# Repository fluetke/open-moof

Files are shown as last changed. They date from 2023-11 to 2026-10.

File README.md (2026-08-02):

---
description: An open resource for DIY repair of the Vanmoof S3.
---

# 👋 Welcome to openMOOF

{% hint style="info" %}
**Work in Progress:** These pages are still a work in progress, ymmv.
{% endhint %}

## Overview

openMOOF collects community knowledge about diagnosing, maintaining, and repairing VanMoof S3 bikes. Use the repair guides for step-by-step procedures, or consult the parts pages when looking for compatible replacements and printable parts.

The manual separates reference data, disassembly, assembly, maintenance, reverse engineering, and supporting files so that measurements and part details can be reused across procedures.

## Quick links

{% content-ref url="overview/what-we-do.md" %}
[Compatible spare parts](overview/what-we-do.md)
{% endcontent-ref %}

{% content-ref url="overview/our-features.md" %}
[3D printable parts](overview/our-features.md)
{% endcontent-ref %}

{% content-ref url="manual/README.md" %}
[Repair manual structure](manual/README.md)
{% endcontent-ref %}

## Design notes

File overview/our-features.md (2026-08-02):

---
description: >-
  The following parts were created by the community and can be 3D printed, there
  is no guarantee for the fit and finish of the printed parts.
---

# ✨ 3D Printable Parts

## Vanmoof S3 spare parts:

* Chainguard rear by manimi94 -> [https://www.thingiverse.com/thing:5386610](https://www.thingiverse.com/thing:5386610)
* Motor-plug cover by lukeabate -> [https://www.thingiverse.com/thing:4713548](https://www.thingiverse.com/thing:4713548)
* Kicklock-cap replacement by Vanmoof4Fun -> [https://www.thingiverse.com/thing:6149896](https://www.thingiverse.com/thing:6149896)
* Handlebar-adjustment rings by fluetke -> [https://www.printables.com/model/538758-handlebar-adjustment-ring-for-vanmoof-s3](https://www.printables.com/model/538758-handlebar-adjustment-ring-for-vanmoof-s3)
* rear-light S2/S3 by fluetke -> [https://www.printables.com/model/535079-rear-light-for-vanmoof-s2s3](https://www.printables.com/model/535079-rear-light-for-vanmoof-s2s3)
* front-fork-stem-assembly S3 by fluetke -> [https://www.printables.com/model/632454-vanmoof-s3-front-fork-stem-assembly](https://www.printables.com/model/632454-vanmoof-s3-front-fork-stem-assembly)

## Vanmoof S3 accessory parts:

* Chaincover clips by Jacob Seifert -> [https://www.printables.com/model/531022-vanmoof-s3-chain-guard-clips](https://www.printables.com/model/531022-vanmoof-s3-chain-guard-clips)
* S3 charger holder by Bouli -> [https://www.printables.com/model/479246-vanmoof-charger-holder-s3-x3](https://www.printables.com/model/479246-vanmoof-charger-holder-s3-x3)
* Kicklock-Cover by Kim Bauters -> [https://www.printables.com/model/632326-vanmoof-x3s3-kick-lock-cap](https://www.printables.com/model/632326-vanmoof-x3s3-kick-lock-cap)
* Boost-Button cover by mvaneijgen -> [https://www.printables.com/model/573768-vanmoof-handle-bar-covers-s3](https://www.printables.com/model/573768-vanmoof-handle-bar-covers-s3)
* handlebar-stand S3 by PjotrStrog -> [https://www.printables.com/model/152812-handlebar-stand-for-vanmoof-s3x3-or-any-bicycle](https://www.printables.com/model/152812-handlebar-stand-for-vanmoof-s3x3-or-any-bicycle)
* &#x20;phone-mount for S2/S3 by fluetke -> [https://www.printables.com/model/205162-phone-mount-for-vanmoof-s2s3s5-v20](https://www.printables.com/model/205162-phone-mount-for-vanmoof-s2s3s5-v20)
* charger wallmount with aircompressor by fluetke -> [https://www.printables.com/model/522243-wall-mount-for-vanmoof-s2-e-bike-charger-with-xiao](https://www.printables.com/model/522243-wall-mount-for-vanmoof-s2-e-bike-charger-with-xiao)
* beer crate holder for rear rack by PjotrStrog -> [https://www.printables.com/model/78128-beer-crate-holder-for-vanmoof-s3-bike-rack-v2](https://www.printables.com/model/78128-beer-crate-holder-for-vanmoof-s3-bike-rack-v2)
* rear-rflector holder for rear-fender by F. Weinmann -> [https://thangs.com/designer/F.%20Weinmann/3d-model/VanMoof%20S3%20Reflektorhalterung-516884](https://thangs.com/designer/F.%20Weinmann/3d-model/VanMoof%20S3%20Reflektorhalterung-516884)

## Parts for other Vanmoof bikes:

* S2 boost button mount by munstudio -> [https://www.thingiverse.com/thing:5535153](https://www.thingiverse.com/thing:5535153)
* S2 charger wallmount by fluetke -> [https://www.printables.com/model/287574-wallmount-for-charger-of-vanmoof-s2](https://www.printables.com/model/287574-wallmount-for-charger-of-vanmoof-s2)

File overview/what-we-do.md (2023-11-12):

---
description: Following is a list of compatible spare parts and (if available) sources.
---

# 💡 Compatible Spare Parts

Pedal cadence sensor: suspected to be this one [https://www.bafang-e.com/uploaded/manual/BF-DM-C-SR%20PA1XX-EN.pdf](https://www.bafang-e.com/uploaded/manual/BF-DM-C-SR%20PA1XX-EN.pdf)  // SR PA12.32.S 6.0

Bell and Boost Buttons - [https://www.amazon.de/Momentanen-Druckschalter-DruckTaster-Wasserdicht-Druckknopf/dp/B08JCG82KT/](https://www.amazon.de/Momentanen-Druckschalter-DruckTaster-Wasserdicht-Druckknopf/dp/B08JCG82KT/) or [https://www.amazon.de/RUNCCI-YUN-Wasserdicht-Druckknopf-Autotrompete-Haustürklingel/dp/B08P4CC8V6/](https://www.amazon.de/RUNCCI-YUN-Wasserdicht-Druckknopf-Autotrompete-Haust%C3%BCrklingel/dp/B08P4CC8V6/)

S3 Crankarm left - Bafang 170mm

S3 Crankarm right - 38T 170mm

gear-plate 5 bolt 110 BCD chainring

source: [https://www.reddit.com/r/vanmoofbicycle/comments/17p548j/s3\_right\_crank\_arm\_set\_what\_model\_is\_it/](https://www.reddit.com/r/vanmoofbicycle/comments/17p548j/s3\_right\_crank\_arm\_set\_what\_model\_is\_it/)

##

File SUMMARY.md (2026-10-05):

# Table of contents

* [👋 Welcome to openMOOF](README.md)

## Repair manual

* [Manual structure](manual/README.md)

### Reference

* [Reference index](manual/reference/README.md)
  * [REF-001 Fasteners](manual/reference/fasteners.md)
  * [REF-002 Torque specifications](manual/reference/torque-specifications.md)
  * [REF-003 Tools](manual/reference/tools.md)
  * [REF-004 Connectors](manual/reference/connectors.md)
  * [REF-005 Bearings and seals](manual/reference/bearings-and-seals.md)
  * [REF-006 Spare parts](manual/reference/spare-parts.md)
  * [REF-007 Recorded firmware history](manual/reference/firmware-history.md)

### Procedures

* [Disassembly](manual/disassembly/README.md)
  * [DEM-003 Drivetrain and bottom bracket](manual/disassembly/drivetrain-and-bottom-bracket.md)
  * [DEM-004 Chassis, controls, and electronics](manual/disassembly/chassis-and-controls.md)
* [Assembly](manual/assembly/README.md)
* [Maintenance](manual/maintenance/README.md)
* [Reverse engineering](manual/reverse-engineering/README.md)
* [Appendix](manual/appendix/README.md)
  * [Community and software resources](manual/appendix/community-and-software-resources.md)

## Vanmoof S3

* [🔢 Error codes](vanmoof-s3/error-codes.md)
* [💡 Compatible Spare Parts](overview/what-we-do.md)
* [✨ 3D Printable Parts](overview/our-features.md)

## Repair Guides

* [🚲 Full disassembly](repair-guides/full-disassembly.md)
* [🧲 Hub-Motor](repair-guides/hub-motor/README.md)
  * [Removing the front wheel and hub motor](repair-guides/hub-motor/removing-the-front-wheel-and-hub-motor.md)
  * [Opening the motor](repair-guides/hub-motor/opening-the-motor.md)
  * [Replacing the planetary gears](repair-guides/hub-motor/replacing-the-planetary-gears.md)
  * [Replacing the hall-sensor](repair-guides/hub-motor/replacing-the-hall-sensor.md)
  * [Motor Connector](repair-guides/hub-motor/motor-connector.md)
* [📪 e-Shifter](repair-guides/e-shifter/README.md)
  * [Manual shifter conversion](repair-guides/e-shifter/manual-shifter-conversion.md)
  * [Set shifter to fixed 3rd gear](repair-guides/e-shifter/set-shifter-to-fixed-3rd-gear.md)
  * [Hub gear miss-alignment](repair-guides/e-shifter/hub-gear-miss-alignment.md)
  * [Error 44 / Communication issues](repair-guides/e-shifter/error-44-communication-issues.md)
* [📎 Cable harness](repair-guides/cable-harness/README.md)
  * [Removing the cable-harness](repair-guides/cable-harness/removing-the-cable-harness.md)
* [💻 Smartcartridge](repair-guides/smartcartridge/README.md)
  * [Replacing the internal speaker](repair-guides/smartcartridge/replacing-the-internal-speaker.md)
* [🔋 Battery](repair-guides/battery.md)
* [Random collection of links](repair-guides/random-collection-of-links.md)

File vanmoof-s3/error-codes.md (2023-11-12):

---
description: >-
  The S3 has a knack for throwing error codes at you, that are not explained in
  the manual or the VM app. Here is a list of most known Error-codes and their
  causes.
---

# 🔢 Error codes

## Err 4 - Battery in deep discharge state

## Err 6 - Battery cells imbalanced / battery fuse blown

## Err 12 - Temperature to low

## Err 16 - Communication with battery lost

## Err 17 - Communication with battery lost/no power

## Err 19 - Internal communication error w/ battery

## Err 20 - Unexpected shutdown of battery

This error results from an unexpected battery shutdown, for instance when you're causing a short somewhere in the bikes electrical system.(I did that while tinkering with the shifter) or the battery is going into protection mode for any other reason.

## Err 21 - Charger not detected/Communication error with charger.

## Err 23 -&#x20;

## Err 40 - Bell button issue

This can happen when you keep pressing the Bell button for a long time or very quickly multiple times. This basically means that the bike has detected an irregularity with your bell button, caused by a short or moisture in the button or a broken wire somewhere.

## Err 41 - Boost button issue

This can happen when you keep pressing the Boost button for a long time or very quickly multiple times. This basically means that the bike has detected an irregularity with your boost button, caused by a short or moisture in the button or a broken wire somewhere.

## Err 44 - Communication with eShifter lost

This Error code points to a loss of communication with the bikes electronic shifter. This is often caused by electronic components on the eShifter PCB failing, sometimes by corrosion of parts due to moisture. See [error-44-communication-issues.md](../repair-guides/e-shifter/error-44-communication-issues.md "mention") for a few hints on diagnosing and fixing this error.

## Err 45 - Communication with motor lost

The error 45 often comes paired with error 48 and idicates a communication issue between the smart-cartridge and the bikes hub-motor. This is a tricky one - possible reasons can be a faulty sensor in the hub-motor(see [hub-motor](../repair-guides/hub-motor/ "mention")) or a broken wire in the bikes wiring harness. While the former is easily fixed by replacing the sensor in question, the latter often requires disassembly of the entire bike to replace or fix the  harness (see [full-disassembly.md](../repair-guides/full-disassembly.md "mention"))

## Err 54 - Sim Card issue

This error comes from your bike not being able to communicate with or detect the simcard inside of the smart cartridge.

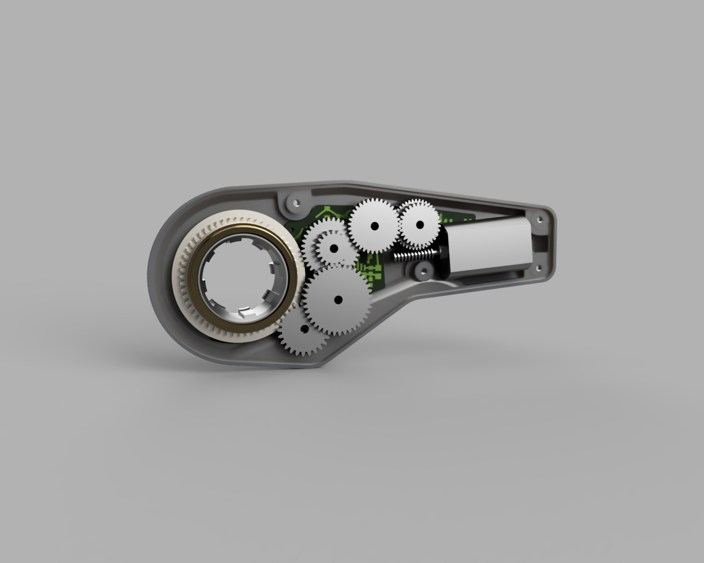
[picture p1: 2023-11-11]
.gitbook/assets/3ae689ba-56e1-4569-a2ad-4a34a7880634.PNG

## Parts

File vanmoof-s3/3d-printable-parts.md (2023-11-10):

---
description: >-
  The following parts were created by the community and can be 3D printed, there
  is no guarantee for the fit and finish of the printed parts.
---

# ✨ 3D Printable Parts

## Vanmoof S3 spare parts:

* Chainguard rear by manimi94 -> [https://www.thingiverse.com/thing:5386610](https://www.thingiverse.com/thing:5386610)
* Motor-plug cover by lukeabate -> [https://www.thingiverse.com/thing:4713548](https://www.thingiverse.com/thing:4713548)
* Kicklock-cap replacement by  -> [https://www.thingiverse.com/thing:6149896](https://www.thingiverse.com/thing:6149896)
* Handlebar-adjustment rings by fluetke -> [https://www.printables.com/model/538758-handlebar-adjustment-ring-for-vanmoof-s3](https://www.printables.com/model/538758-handlebar-adjustment-ring-for-vanmoof-s3)
* rear-light S2/S3 by fluetke -> [https://www.printables.com/model/535079-rear-light-for-vanmoof-s2s3](https://www.printables.com/model/535079-rear-light-for-vanmoof-s2s3)
* front-fork-stem-assembly S3 by fluetke -> [https://www.printables.com/model/632454-vanmoof-s3-front-fork-stem-assembly](https://www.printables.com/model/632454-vanmoof-s3-front-fork-stem-assembly)

## Vanmoof S3 accessory parts:

* Chaincover clips by -> [https://www.printables.com/model/531022-vanmoof-s3-chain-guard-clips](https://www.printables.com/model/531022-vanmoof-s3-chain-guard-clips)
* S3 charger holder by Bouli -> [https://www.printables.com/model/479246-vanmoof-charger-holder-s3-x3](https://www.printables.com/model/479246-vanmoof-charger-holder-s3-x3)
* Kicklock-Cover by -> [https://www.printables.com/model/632326-vanmoof-x3s3-kick-lock-cap](https://www.printables.com/model/632326-vanmoof-x3s3-kick-lock-cap)
* Boost-Button cover by -> [https://www.printables.com/model/573768-vanmoof-handle-bar-covers-s3](https://www.printables.com/model/573768-vanmoof-handle-bar-covers-s3)
* handlebar-stand S3 by -> [https://www.printables.com/model/152812-handlebar-stand-for-vanmoof-s3x3-or-any-bicycle](https://www.printables.com/model/152812-handlebar-stand-for-vanmoof-s3x3-or-any-bicycle)
* &#x20;phone-mount for S2/S3 by fluetke -> [https://www.printables.com/model/205162-phone-mount-for-vanmoof-s2s3s5-v20](https://www.printables.com/model/205162-phone-mount-for-vanmoof-s2s3s5-v20)
* charger wallmount with aircompressor by fluetke -> [https://www.printables.com/model/522243-wall-mount-for-vanmoof-s2-e-bike-charger-with-xiao](https://www.printables.com/model/522243-wall-mount-for-vanmoof-s2-e-bike-charger-with-xiao)
* beer crate holder for rear rack -> [https://www.printables.com/model/78128-beer-crate-holder-for-vanmoof-s3-bike-rack-v2](https://www.printables.com/model/78128-beer-crate-holder-for-vanmoof-s3-bike-rack-v2)

## Parts for other Vanmoof bikes:

* S2 boost button mount by -> [https://www.thingiverse.com/thing:5535153](https://www.thingiverse.com/thing:5535153)
* S2 charger wallmount by fluetke -> [https://www.printables.com/model/287574-wallmount-for-charger-of-vanmoof-s2](https://www.printables.com/model/287574-wallmount-for-charger-of-vanmoof-s2)

{% hint style="info" %}
**GitBook tip:** A succinct video overview is a great way to introduce folks to your product. Embed a Loom, Vimeo or YouTube video and you're good to go! We love this video from the fine folks at Loom as a perfect example of a succinct feature overview.
{% endhint %}

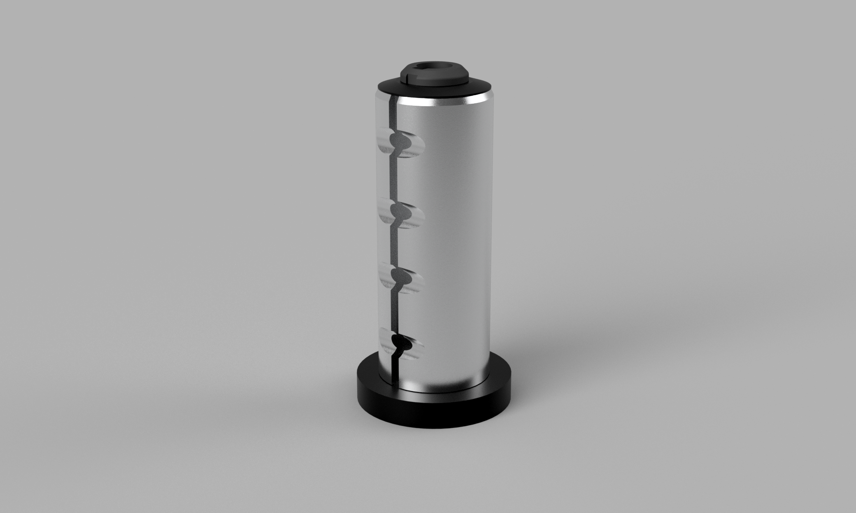
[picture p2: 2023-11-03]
parts/openMoof_stemRetentionCapv2.png

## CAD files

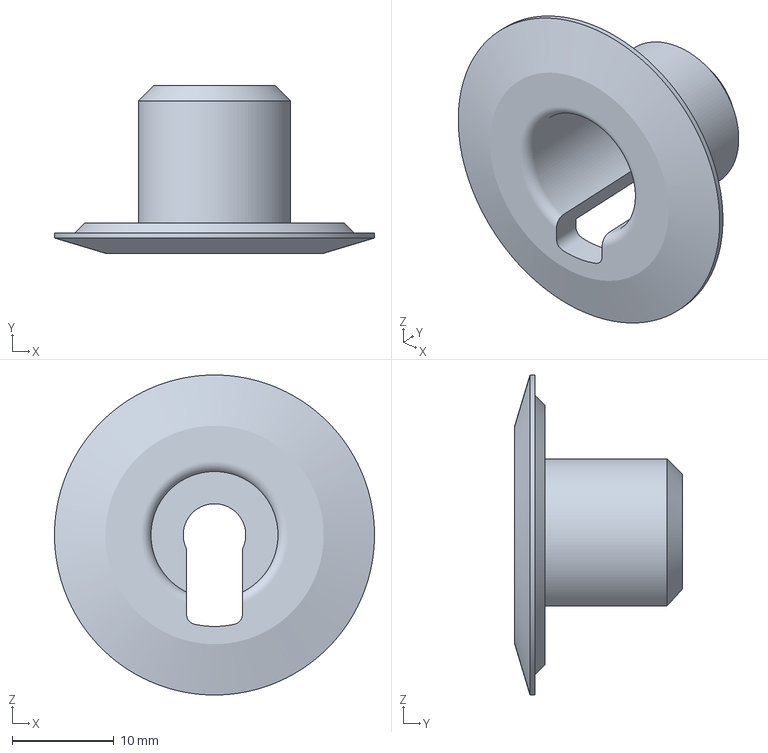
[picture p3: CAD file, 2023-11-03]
parts/stem_retention_cap.3mf
31.5 x 16.5 x 31.5 mm

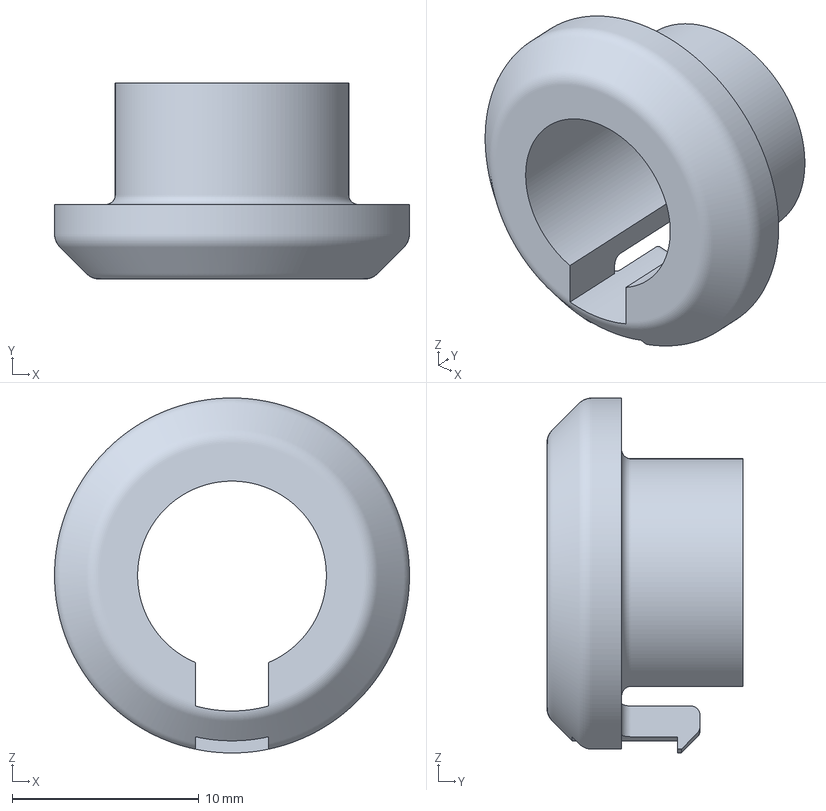
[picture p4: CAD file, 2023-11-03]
parts/cable_retention_cap.3mf
19.0 x 10.5 x 19.0 mm

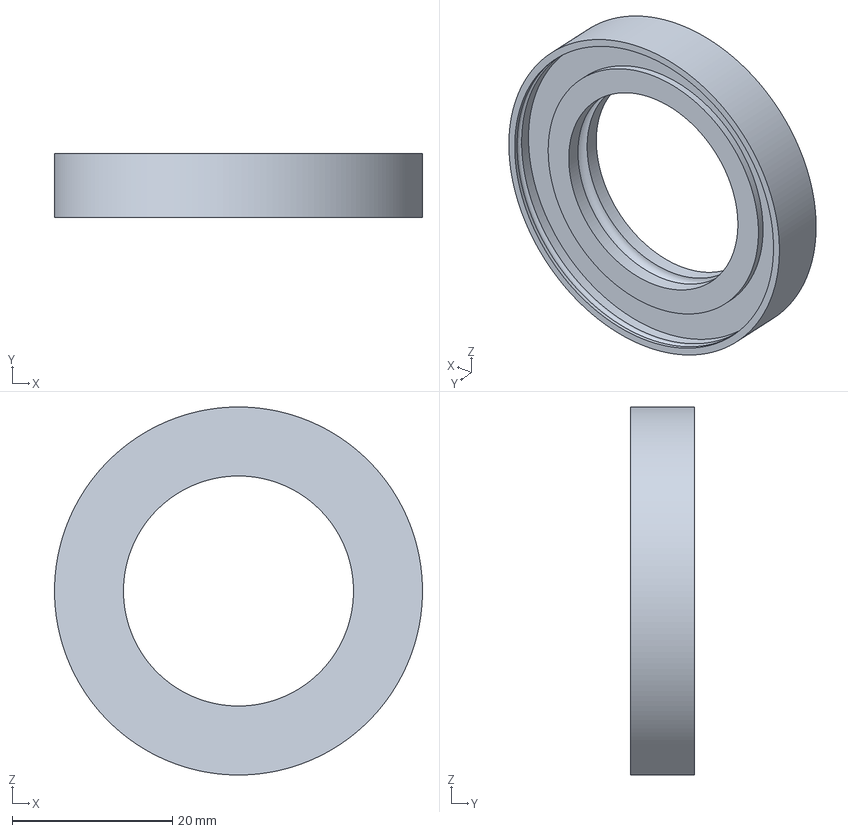
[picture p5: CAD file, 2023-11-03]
parts/stem_sealing_ring.3mf
46.0 x 8.00 x 46.0 mm

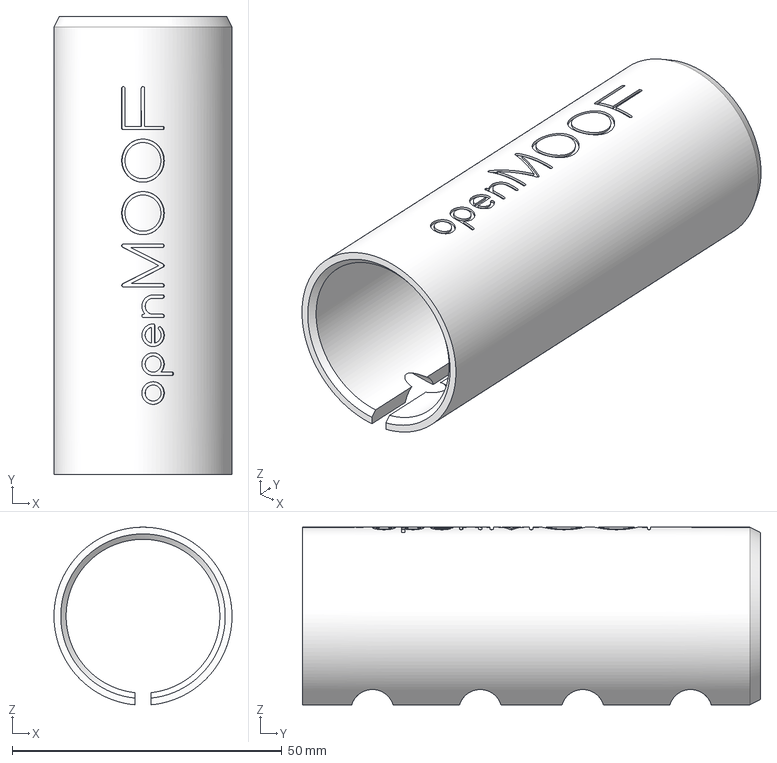
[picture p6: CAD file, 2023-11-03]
parts/handlebar_adjustment_sleeve.3mf
33.0 x 85.0 x 32.9 mm

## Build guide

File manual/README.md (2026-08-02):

---
description: How the openMOOF VanMoof S3 repair and service manual is organized.
---

# Manual structure

The manual is divided into six areas. This keeps reusable specifications separate from procedures while giving workshop findings and supporting files a permanent home.

| Area | Purpose |
| --- | --- |
| [Reference](reference/README.md) | Fasteners, torque specifications, tools, connectors, bearings, seals, and spare parts |
| [Disassembly](disassembly/README.md) | Chronological removal procedures |
| [Assembly](assembly/README.md) | Reassembly in reverse order, with links to reference data |
| [Maintenance](maintenance/README.md) | Cleaning, lubrication, inspection, and preservation |
| [Reverse engineering](reverse-engineering/README.md) | Construction, materials, weaknesses, measurements, and community-developed parts |
| [Appendix](appendix/README.md) | Parts lists, photographs, CAD models, and printable files |

## Document identifiers

Use a stable identifier when adding an individual document:

* `REF-###` for reference material
* `DEM-###` for disassembly procedures
* `MON-###` for assembly procedures
* `WAR-###` for maintenance procedures
* `RE-###` for reverse-engineering records

The number identifies the document and should not be reused if a page is later removed. Human-readable filenames and titles should follow the identifier.

## Procedure records

Record the following information whenever it is known and applicable:

| Field | Description |
| --- | --- |
| Tool | Required wrench, socket, bit, puller, or other tool |
| Torque | Manufacturer specification or a value verified in practice; clearly identify which |
| VanMoof part number | Original part number, if known |
| Related chapter | Relevant disassembly or assembly procedure |
| Photograph | A reference image that clearly identifies the part or fastener |

{% hint style="warning" %}
Do not present an estimated torque or an unverified part identification as a manufacturer specification. Label the source and verification status of workshop data.
{% endhint %}

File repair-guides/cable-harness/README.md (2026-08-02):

---
description: Oh Boy, this one's a hard piece of work.
---

# 📎 Cable harness

## Replacing the cable harness

To replace the harness, you need to remove EVERY SINGLE PART from your bike.

Start by removing the rear wheel and eShifter as described in the [e-Shifter guide](../e-shifter/README.md "mention")

Proceed by removing the front wheel and hub motor as describe in [removing-the-front-wheel-and-hub-motor.md](../hub-motor/removing-the-front-wheel-and-hub-motor.md "mention")

With booth wheels removed, go ahead and remove the saddle (easy done using the torx 0 screw on the seatpost with the torx wrench in your Vanmoof toolkit).

After you've removed the saddle it's time to slide out the smart cartridge, the heart of your smartbike. To do so, remove the size 8 SecurityTorx screw below the upper crossbar. Pay attention there is one small antenna plate that needs to be removed as well, it is held on with 2 silver Security Torx screws. Dont remove the frontmost pair of torx screws yet. Once all screws are removed slide the cartridge out of the back of the bike.

Next, either hang your bike from the ceiling or turn it upside down to access the battery.

Removing the battery is quite easy, there are 3 security torx screws holding the battery cover plate onto the bottom frame. Remove the side and the center screw and you will be able to remove the cover plate. Don't leave the center screw in and think you can pull out the battery with the plate attached. The wire for the pedal-sensor runs right in between the plate and the actual battery, you'll risk damaging it. Fully remove all three screws before you remove the plate.&#x20;

With the plate removed you'll see the actual battery and the sensor cable running across it.

Lightly pull on the sensor cable to reveal the sensor connector.

Disconnect the pedal sensor and move the wire out of the way. Then lift up the small handle and pull out the battery. This shouldn't require much force, if the battery is stuck, you might want try to put just the center screw back and use pliers or a wrench to pull the battery out by holding onto the screw. Be careful, the heatset insert for the screw will give in after a while of prying, after which you wont be able to pull the battery out at all.

After removing the battery you'll be able to reach the wires for kicklock and eShifter.

Before you try to pull the wires out, first remove the kicklock, as described in Vanmoofs Video here: [https://www.youtube.com/watch?v=fQxvvyrIWjA](https://www.youtube.com/watch?v=fQxvvyrIWjA\&pp=ygUUdmFuIG1vb2YgczMga2lja2xvY2s%3D)

When this is done you can slowly pull out the wires going to kicklock and the eShifter.&#x20;

Next, remove the cable guide inside the frame. There should be a dark-grey plastic piece in the battery compartment which you can slide out by slowly pulling on it with a pair of pliers.

Next, turn your bike back around, if you've flipped it previously, or lower it a bit if hung from the ceiling. You'll want to remove the handlebar and front fork next.

To remove the handlebar, unscrew the two hex-screws you've used to set the handlebar height and secure it to the bike when you first received your Vanmoof. Then lift up the handlebar and remove the spacers you might've installed. Be carefully when pulling up the handlebar as there are two small wires running inside of it. Those connect your bell and boost buttons to the rest of the bike. You can disconnect them with two small plugs on the cables. Just make note of which cable goes where.

Next disconnect the two hydraulic brake lines going to your brake levers, careful, this will spill a bit of oil, so make sure to keep a towel nearby. Wrap them in a bit of plastic to prevent further spills and protect the ends of the lines. You can now fully remove the handebar.

Afterwards remove the screw in the central pinion of the front fork, but be careful when doing so, as this screw keeps your bikes front fork in place. After removing the screw, slide up the metal sleeve that goes over your front fork. Your fork might fall out any moment now.

To remove the front fork, slowly push down on the forks pinion, while turning the fork left and right. You should be feeling the fork come loose slowly. At this point, STOP!&#x20;

Before going any further make sure you have a bit of string ready. Tie the string around the motor plug and the two small wires coming out of the top of the fork. Then slowly push the motor-plug and the small cables into the fork, to enable them to slide out easily when you continue pushing down the fork. To make things a little easier and increase your visibility during the next steps, you might want to also remove the headlight, this will give you access to the back of the cartridge and battery sockets and allow you to see more clearly how your removal operation goes.

Continue turning and pushing the fork until it fully drops out of your bikes frame.

You should now have an empty frame with three wires dangling out of the lower front of your bike.

Time to tackle the main task, removing the socket and cable harness. You've already prepared the bottom cables, good on you. Now is the time to remove the remaining screws from below the top crossbar. These securtiy torx are in a tight spot, you might want to combine a bit and a wrench to get these out, they are holding the cartridge socket in place. Repeat this process with the two screws on the bottom crossbar, which hold the battery connector in place.

With all four screws removed you should be able to pull the complete socket out of the lower front of your bike, below where the headlight used to be.

Now simply repeate the process in reverse to insert the new harness. ;-P

Some tips:&#x20;

First of all - Putting the harness back is nowhere near as easy as taking it out.

When inserting the cartridge socket and battery socket, hold them in place by using two of your longest fingers through the headlight hole and/or the bottom hole where the fork goes.

You might want to prepare the wires for the battery and the brakelines by 3d printing fitting inserts for the battery compartment which will hold the brake line in place, next to the cable harness, so you can more easily insert the plastic shim that holds all of this in place later.

If you need to use brute force for something, you're doing it wrong.

Take a break, go boxing to get rid of your rising aggression and try again the next day. And believe me, you will get quite aggressive when trying to replace this pos without a manual.

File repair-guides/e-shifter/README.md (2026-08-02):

---
description: How to fix the Vanmoof e-Shifter and with it the dreaded error 44.
---

# 📪 e-Shifter

## Possible e-Shifter Errors

* Error in communication of eShifter and smart cartridge, see [error-44-communication-issues.md](error-44-communication-issues.md "mention")
* wrong alignment of eShifter hub gear
* faulty hall-effect sensor for gear selection

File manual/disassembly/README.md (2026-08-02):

---
description: Chronological disassembly procedures for the VanMoof S3.
---

# Disassembly

Disassembly documents follow the chronological order in which parts are removed from the bicycle. Each procedure should identify prerequisites, tools, fasteners, electrical or hydraulic connections, hazards, and the storage or labelling needed for removed parts.

The current [full-disassembly record](../../repair-guides/full-disassembly.md) will become the top-level sequence. Existing component procedures provide detailed steps for:

* [removing the front wheel and hub motor](../../repair-guides/hub-motor/removing-the-front-wheel-and-hub-motor.md)
* [opening the hub motor](../../repair-guides/hub-motor/opening-the-motor.md)
* [removing the cable harness](../../repair-guides/cable-harness/README.md)

New chronological procedures should use `DEM-###` identifiers and link to the applicable fastener, tool, connector, and torque references.

Workshop-log procedures are now consolidated in:

* [drivetrain and bottom bracket](drivetrain-and-bottom-bracket.md)
* [chassis, controls, and electronics](chassis-and-controls.md)

## Battery removal workshop findings

During one documented S3 repair, the rear tyre was deflated before the battery was successfully removed. The exposed interior appeared clean after removal. This observation comes from repair audio notes and is **not yet a complete removal procedure**: the reason for deflating the tyre, the required pressure, omitted prerequisite steps, and the battery's removal direction remain to be verified.

## Kickstand removal workshop findings

The kickstand was removed with an [8 mm hex key](../reference/tools.md#tool-register). Slight or incipient corrosion was found in the kickstand area. The precise location, condition and number of its fasteners, and the required torque were not captured. See the [maintenance guidance](../maintenance/README.md#kickstand-corrosion) before reassembly.

## Front hub motor inspection finding

After loosening the front axle nuts, the hub motor was checked for free rotation. On the documented bicycle it continued to rotate freely and felt subjectively as good as usual. Record the order of the axle nuts and washers during removal because their exact arrangement has not yet been documented. See the [assembly warning](../assembly/README.md#front-hub-motor-axle) before installing the wheel.

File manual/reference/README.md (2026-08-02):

---
description: Shared technical reference data for VanMoof S3 service procedures.
---

# Reference index

Reference pages hold facts that are reused by multiple procedures:

* [REF-001 Fasteners](fasteners.md)
* [REF-002 Torque specifications](torque-specifications.md)
* [REF-003 Tools](tools.md)
* [REF-004 Connectors](connectors.md)
* [REF-005 Bearings and seals](bearings-and-seals.md)
* [REF-006 Spare parts](spare-parts.md)
* [REF-007 Recorded firmware history](firmware-history.md)

Each entry should cite the procedure or workshop record from which it was obtained. Measurements must include units, and manufacturer data must be distinguishable from values verified in practice.

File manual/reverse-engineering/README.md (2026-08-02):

---
description: Construction observations, failure points, measurements, and candidates for improved S3 replacement parts.
---

# Reverse engineering

All material identifications on this page are visual workshop hypotheses until tested.

## Chain tensioner

The moulded housing concentrates mounting and closure load at a small eye; two eyes were broken and multiple microcracks were visible. A replacement design must preserve chain line, spring preload and stops, bearing fits, guard clearance, and fastener stack. Capture dimensions, photographs, fracture surfaces, spring rate, loads, and the full `689 RS` bearing marking before modelling. Do not copy the weak eye without structural validation.

## Chain cover

The 38-tooth chainring's cover is clipped on after crank removal. Its lower arm and several retaining tabs were broken and the plastic had aged. It may be glass-filled polyamide, but this is unverified. Its size may require a modular printable design; determine material, measurements, joining method, heat/chemical resistance, and chain clearance first. An official replacement was listed in the source notes for €25, but price and availability are time-sensitive.

## Bottom bracket and frame

The Bafang assembly uses a left keyed support whose tabs prevent rotation and a right left-threaded protective cup. The cracked right and good left removable seals may be standard Bafang items; confirm profiles and dimensions before cross-referencing. The bottom-bracket shell includes a deliberate water drain.

## Handlebar and controls

The bar appeared to combine a machined aluminium casting with a bent welded tube, but neither material nor process is confirmed. Replacement grips must reproduce the button-wire groove and leave room for the cable, silicone-mounted button, retaining set screw, lever clamp, and steerer clearance. Record spacer count and cable route before developing replacements.

## Other identification records

* Crank: forged, 170 mm, `GJ-9AS`; five-bolt, replaceable 38-tooth ring.
* Pedals: right `CM-R0H2`; left marking uncertain.
* Brake calipers: front `J19 8380`; rear `J19 7901`.
* Kick Lock bolt: visually stainless with an unidentified black centre insert.

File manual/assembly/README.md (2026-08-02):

---
description: Reassembly procedures for the VanMoof S3.
---

# Assembly

Assembly follows the reverse order of disassembly but must be documented as an explicit procedure rather than relying on “reverse the previous steps.” Include cable and hose routing, connector checks, lubrication, fastener replacement requirements, tightening sequence, torque, adjustment, and a final functional test.

Use `MON-###` identifiers for assembly procedures. Link every step to the relevant [fastener](../reference/fasteners.md), [torque](../reference/torque-specifications.md), [tool](../reference/tools.md), and [connector](../reference/connectors.md) records.

## Front hub motor axle

The front-wheel axle is also the hub motor axle. A shaped feature on the axle acts as a mechanical anti-rotation feature: when correctly seated in the corresponding fork dropout, it prevents the axle from rotating relative to the fork while the motor drives the wheel. A transcript reference to a retaining tab describes this axle feature, **not a tab on a washer**. The front axle washers observed during the repair were completely round.

{% hint style="danger" %}
When installing the front hub motor, fully seat the axle's anti-rotation feature in the matching fork dropout before tightening the axle nuts. An incorrectly seated axle can rotate relative to the fork under motor torque.
{% endhint %}

Keep every washer in its recorded position and order. The number, dimensions, material, exact installation order, axle and dropout geometry, and applicability of the recorded [front axle nut torque](../reference/torque-specifications.md#manufacturer-specified-torques) to the observed configuration must still be verified.

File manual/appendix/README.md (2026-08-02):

---
description: Supporting parts lists, photographs, CAD models, and printable files.
---

# Appendix

The appendix collects supporting material that does not belong in the procedural flow:

* parts lists
* reference photographs
* CAD files
* STL and other printable model files

The repository's current printable models are stored in [`parts/`](../../parts/), with preview and source information on the [3D printable parts](../../overview/our-features.md) page. Use descriptive filenames and link each asset back to its related procedure or reverse-engineering record.

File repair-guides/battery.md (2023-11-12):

---
description: Everything concerning the S3s battery
---

# 🔋 Battery

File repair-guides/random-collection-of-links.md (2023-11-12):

# Random collection of links

{% embed url="https://www.youtube.com/watch?v=BZty5RE1cLk" %}

{% embed url="https://www.reddit.com/r/vanmoofbicycle/comments/w78lln/stuck_gear_actuator_ring/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" %}

{% embed url="https://www.reddit.com/r/VanMoofSelfRepair/comments/16iwmdn/s3_sturmey_archer_and_eshifter_assembly_specs/" %}

[https://keeponmoofing.nl/](https://keeponmoofing.nl/) -> improved eshifter pcb

{% embed url="https://www.reddit.com/r/VanMoofSelfRepair/comments/16idefs/replacement_bms_for_s3_battery/" %}

{% embed url="https://github.com/stefanstranger/vanMoof" %}

{% embed url="https://amzn.eu/d/illdboY" %}

{% embed url="https://www.reddit.com/r/VanMoofSelfRepair/comments/161ekpy/brake_liquid_and_pads_for_s3/" %}

&#x20;replacing eshifter with shimano alphine -> [https://alexander-degreiff.medium.com/diy-custom-vanmoof-s3-with-shimano-alfine-manual-gear-shift-6ee6d350a27](https://alexander-degreiff.medium.com/diy-custom-vanmoof-s3-with-shimano-alfine-manual-gear-shift-6ee6d350a27)

Connector type: 150 G6.5.4

bottom sensor -> [https://www.reddit.com/r/VanMoofSelfRepair/comments/169zcyl/is\_that\_the\_right\_bottom\_bracket\_for\_an\_s3/](https://www.reddit.com/r/VanMoofSelfRepair/comments/169zcyl/is\_that\_the\_right\_bottom\_bracket\_for\_an\_s3/)

{% embed url="https://www.youtube.com/watch?v=2poD8W8kmVU" %}

{% embed url="https://www.reddit.com/r/VanMoofSelfRepair/comments/16cdhuf/brake_reservoir_diaphragm_replacement_s3/" %}

{% embed url="https://www.ifixit.com/Guide/VanMoof+S3+Bell+Button+Replacement/138539" %}

{% embed url="https://github.com/Tenkir/vanmoof-s2-user-manual" %}

{% embed url="https://u.pcloud.link/publink/show?code=kZqCYAVZkf9BIvqq7F8hjSvXMIWvrppAAt1V" %}
battersea
{% endembed %}

{% embed url="https://www.reddit.com/r/VanMoofSelfRepair/comments/151w8er/manual_for_motor_cable_connector_refitting/" %}

{% embed url="https://www.reddit.com/r/VanMoofSelfRepair/comments/1512n4t/the_arduino_powered_vanmoof/" %}

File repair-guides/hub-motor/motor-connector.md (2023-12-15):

---
description: >-
  The motor is connector to the rest of the bike with a hard to come by
  connector from Higo with 11-pins.
---

# Motor Connector

The motor is connected to the smart-cartridge with an 11-pin Higo connector, model Z1115A.([https://www.higoconnector.com/products/z1115ag-p-00-du-1000/LZ99K](https://www.higoconnector.com/products/z1115ag-p-00-du-1000/LZ99K))

However, not all pins of the connector are used, actually only 6 pins are in use.

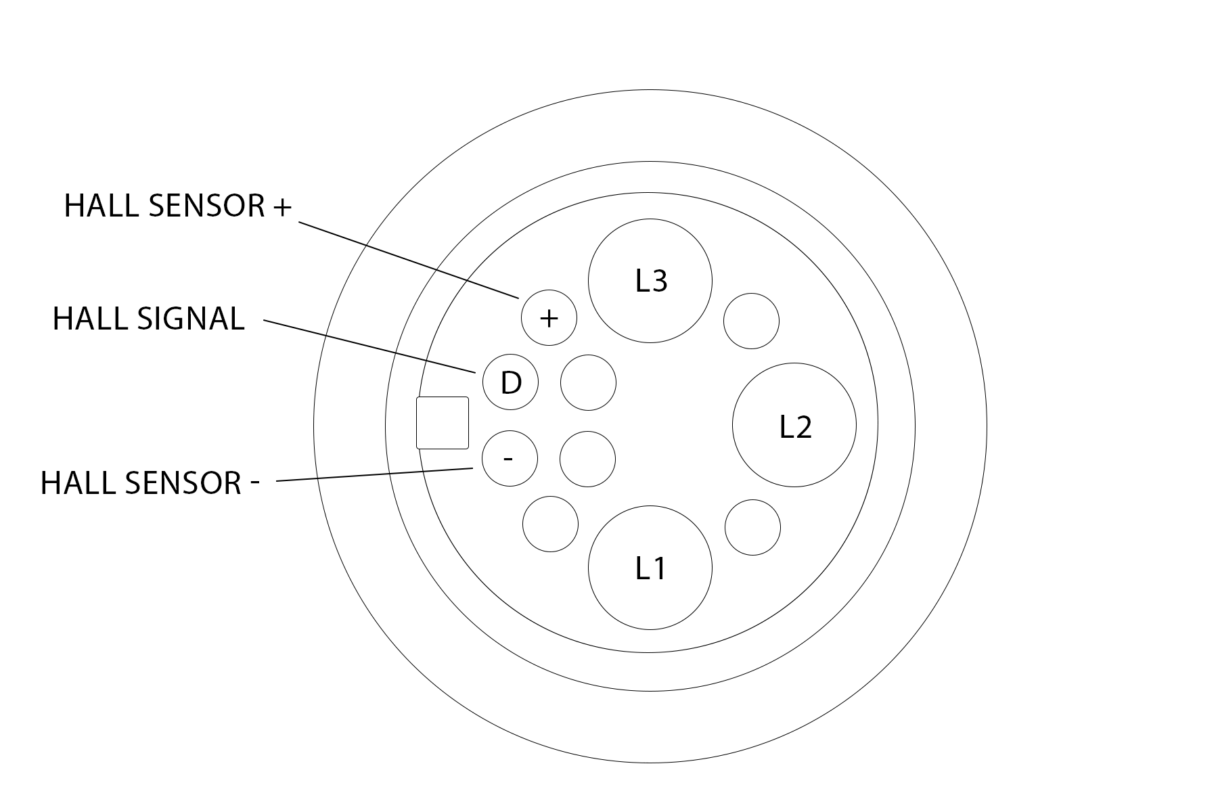
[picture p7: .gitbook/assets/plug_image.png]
<figure><figcaption></figcaption></figure>

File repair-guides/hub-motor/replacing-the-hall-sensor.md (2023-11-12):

---
description: >-
  Often the cable-harness is not the only reason for a missing speed reading.
  The hall-sensor in the hub motor can be defective too.
---

# Replacing the hall-sensor

After opening the hub motor, the small hall sensor board is instantly visible.&#x20;

Schematic of the sensor-board.

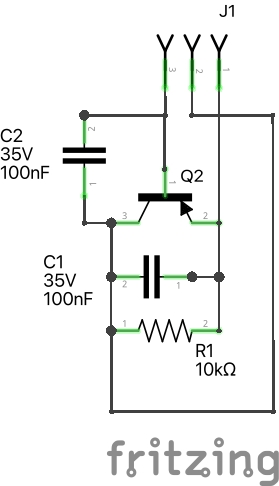
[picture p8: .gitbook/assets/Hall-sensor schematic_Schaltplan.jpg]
<figure><figcaption><p>sensor board schematic</p></figcaption></figure>

Source: [https://www.reddit.com/r/VanMoofSelfRepair/comments/17a4r2i/fixing\_s3\_hub\_motor\_hall\_sensor\_schematic/](https://www.reddit.com/r/VanMoofSelfRepair/comments/17a4r2i/fixing\_s3\_hub\_motor\_hall\_sensor\_schematic/)

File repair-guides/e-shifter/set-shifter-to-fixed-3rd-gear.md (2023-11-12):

---
description: >-
  The following how-to by reddit user /u/wiliv explains how to set the eShifter
  and rear hub to a fixed 3rd gear, in case you want to ride your bike as
  "fixie" without using the eShifter going forward.
---

# Set shifter to fixed 3rd gear

1. Removing the rear wheel and e-shifter: I accomplished both of these tasks using the tools provided with my bike along with 4 mm and 2.5 mm hex keys. VanMoof has YouTube videos for both of these tasks and I was able to follow them without issue.
2. Taking apart the e-shifter: it is held together with four screws that require a 2 mm hex key. The two halves are sealed with a rubber gasket and you'll need to use some sort of shim to separate them (I used a plastic bicycle tire remover shim). Separating them with the corded side up will yield the layout you see an image 1. Again, there are videos on YouTube of folks doing this if you want to see how it's done.
3. Positioning the e-shifter in third gear: With the electric motor separated from the gear train, I was able to easily rotate the output spline to the third gear position, image 2. I then put the two halves back together and then separated them again, this time with the corded side down so that all of the components were laying in the same half of the housing, image 3.
4. Aligning hub: The black gear on the hub is the input to the hub shifter. The range of motion between first and fourth gear is about 90°, with approximately 30° increments between each gear. I rotated it back and forth across its full range of motion to get familiar with it and then tried to place it at approximately the third gear position (60° counterclockwise from first gear). The axle must be held in place while you do this else the whole assembly will spin. I then placed the e-shifter onto the hub like you see in image 3 and verified that the spline of the e-shifter meshed with the hub. Lastly, I took the outer shell of the e-shifter and slid it over the axle and aligned the two halves of the e-shifter like you see in image 5, eventually snugging them together once they were aligned. This was probably more tedious than it needed to be, but it verified both that the spline had proper engagement and that the relative position of the axle and the hub gear were correct.
5. Reassembly: I removed the e-shifter from the hub and put it back together with its four screws. I then reattach the e-shifter and reinstalled the rear wheel, again following the YouTube videos provided by VanMoof.
6. Testing: My biggest concern with this alteration is accidentally positioning the hub shifter between gears. With the bike upside down, I hand peddled it and listened for any abnormal clicking or grinding noises. Hearing none, I took it for a test drive to confirm that I could comfortably pedal at the top speed as well as comfortably accelerate from a stop with the aid of the boost button.

Source: [https://www.reddit.com/r/vanmoofbicycle/comments/14x90pd/s3fixie\_stopgap/](https://www.reddit.com/r/vanmoofbicycle/comments/14x90pd/s3fixie\_stopgap/)

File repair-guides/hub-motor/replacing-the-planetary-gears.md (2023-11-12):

# Replacing the planetary gears

The internal gears of the motor are mare from nylon plastic and are apparently wearing down quite quickly. Fortunately, spare parts for these gears are readily available from AliExpress.&#x20;

The replacement part you're looking for is "100SX 39Tx27T Left" available here:  [https://de.aliexpress.com/item/4000083060603.html](https://de.aliexpress.com/item/4000083060603.html?bizType=ProductDetail)

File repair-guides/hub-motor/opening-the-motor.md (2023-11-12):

# Opening the motor

Open the motor is quite easy, you'll need a Torx wrench and a Phillips screwdriver.

1. With the front hub removed, place the wheel on its side, the side with screws facing upward.
2. Remove the screws securing the brake disc to the wheel and put it aside.
3. Remove the screws around the outer side of the hub with the Torx wrench, opening the screws on opposing sides in pairs, to even out the pressure along the hub.
4. With the screws removed carefully slide the cap upwards to open up the motor housing. It should've come apart already through the pressure from the motor pushing against it.
5. You can now remove the motor from it's housing, by pulling it up and carefully guiding the motor cable through the rear hole of the hub.

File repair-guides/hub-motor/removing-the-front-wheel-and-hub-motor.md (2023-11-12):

---
description: >-
  Removing the front wheel and hub motor is one of the prerequisites to many
  repairs concerning communication issues.
---

# Removing the front wheel and hub motor

Luckily this process is relatively straight forward, just follow along with the official video by VanMoof and you should be good to go.

{% embed url="https://www.youtube.com/watch?v=opYEO-5hEkI" %}
Source: [VanMoof Youtube Channel](https://www.youtube.com/@vanmoof)
{% endembed %}

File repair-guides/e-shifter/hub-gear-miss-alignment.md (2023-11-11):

---
description: >-
  If you don't have Err 44 and your cartridge indicates a shift which doesn't
  happen, there is a high chance that you have a miss-aligned hub gear.
---

# Hub gear miss-alignment

Your eShifter does try to realign itself on every startup. If you have an extreme miss-alignment of your central shift gear, the automated process will fail leaving you with an inoperable eShifter.&#x20;

Don't worry, the fix is quite easy.&#x20;

1. Remove the rear wheel with the eShifter, following this video by Vanmoof.\

{% embed url="https://www.youtube.com/watch?v=qehoD-6xbkI" %}

1. Remove the eShifter from the rear wheel, following this video by Vanmoof.&#x20;

{% embed url="https://www.youtube.com/watch?v=FyDecZQhlAw" %}

1. In the video you can already see the auto-alignment process. If your eShifters alignment process fails, you need to disassemble the eShifter.
2. Remove the 4 screws holding the shifter together, and split it apart along the seam. There is an easy location at the bottom of the shifter, where you can wedge in a small screwdriver.
3. Lay the eShifter flat on a table and slowly lift off the front shell.&#x20;
4. You'll see the eShifter PCB and the central gear on the left side of the shifter. Take a look at the ring around the main gear. Notice the small black markings in the ring? These are small magnets, which are supposed to trigger the hall-effect sensors on the eShifters board.&#x20;
5. That your shifters alignment process failed, can basically have two causes:&#x20;
   1. one or both of your hall-effect sensors are faulty.
   2. the main gear was aligned so bad, that it triggered the expected response from the hall-effect sensors before reaching its correct position.
6. If your sensors are indeed faulty, you'll need to replace them with the correct hall effect sensor type and try again.&#x20;
7. If your main gear is missaligned, you can fix the shifter by taking out one of the smaller gears of the shifter, so that the main gear can "freely" rotate (it's pretty tightly pressed into the bushings, so it might take a bit of force to spin it, but it should be able to spin without affecting the gears all the way back to the motor). Then rotate the main gear until the small dot on the gear aligns with the dot on the shifters housing.&#x20;
8. Reassemble the shifter.
9. Plug the shifter back into the bike and turn on the bike.
10. You should see the shifter rotate from its position and realign itself successfully.
11. You can now turn off the bike again, unplug the shifter and reattach it to the wheel, as described in the video "Replacing the eShifter" linked above.
12. Finally reattach the wheel to your bike, as described in the video below:

{% embed url="https://www.youtube.com/watch?v=BdIeioy5_4A" %}

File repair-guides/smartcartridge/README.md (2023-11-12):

---
description: Everything related to the S3 smart cartridge
---

# 💻 Smartcartridge

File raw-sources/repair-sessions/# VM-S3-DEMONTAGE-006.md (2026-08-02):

# VM-S3-DEMONTAGE-006  
## Demontage der rechten Kurbel (Antriebsseite)  
  
### Metadaten  
  
| Feld | Wert |  
|---|---|
| Baugruppe | Kurbel / Tretlager |  
| Status | [BESTÄTIGT] |  
| Informationsquelle | Nachträglich rekonstruierte Sprachnotiz |  
  
---  
  
## Ziel  
  
Entfernen der rechten Kurbel (Antriebsseite), um anschließend Zugang zum Tretlager und den dahinterliegenden Baugruppen zu erhalten.  
  
---  
  
## Benötigtes Werkzeug  
  
| Werkzeug | Verwendung |  
|---|---|
| 8-mm-Inbusschlüssel | Entfernen der Kurbelschraube (bereits zuvor erfolgt) |  
| Kurbelabzieher (Fengzeo) | Abziehen der Vierkantkurbel |  
| 16-mm-Maulschlüssel | Gegenhalten des Kurbelabziehers |  
  
---  
  
## Demontage  
  
### 1. Kurbelabzieher einsetzen  
  
`[BESTÄTIGT]`  
  
Der äußere Gewindekörper des Kurbelabziehers wird vollständig in das Innengewinde des Kurbelarms eingeschraubt.  
  
Anschließend wird die Druckspindel des Werkzeugs gegen die Tretlagerachse gedreht.  
  
---  
  
### 2. Kurbel abziehen  
  
`[BESTÄTIGT]`  
  
Zum Drehen der Druckspindel wurde ein **16-mm-Maulschlüssel** verwendet.  
  
Während des Abziehens wurde der Kurbelarm mit der freien Hand stabilisiert.  
  
Zum Lösen des Presssitzes ist ein spürbarer Kraftaufwand erforderlich.  
  
Nach ausreichendem Anziehen der Druckspindel löst sich der Kurbelarm kontrolliert von der Vierkantachse.  
  
> **Werkstatt-Hinweis**  
>  
> Das Lösen der Vierkantkurbel erfordert deutlich mehr Kraft als zunächst erwartet. Dieses Verhalten erscheint aufgrund des konischen Presssitzes normal.  
  
---  
  
## Kettenschutz  
  
`[BESTÄTIGT]`  
  
Nach dem Entfernen der rechten Kurbel lässt sich der Kettenschutz ohne Werkzeug entfernen.  
  
Der Kettenschutz ist lediglich aufgesteckt und wird nicht zusätzlich verschraubt.  
  
---  
  
## Beobachtung am Tretlager  
  
`[BESTÄTIGT]`  
  
Nach Entfernen des Kettenschutzes wird um das eigentliche Tretlager eine ringförmige Dichtung beziehungsweise ein gummiartiges Bauteil sichtbar.  
  
Dieses besitzt eine gezahnte beziehungsweise profilierte Kontur.  
  
---  
  
## Vermutung  
  
`[UNSICHER]`  
  
Die Verzahnung ähnelt der Aufnahme eines Tretlagerwerkzeugs.  
  
Zum Zeitpunkt der Demontage konnte jedoch noch nicht sicher beurteilt werden,  
  
- ob dieser Ring Bestandteil des Tretlagers ist,  
- ob er zunächst entfernt werden muss,  
- oder ob das eigentliche Tretlagerwerkzeug direkt an dieser Verzahnung ansetzt.  
  
Aus diesem Grund wurde das Bauteil zunächst nicht demontiert.  
  
---  
  
## Abschluss der Arbeiten  
  
`[BESTÄTIGT]`  
  
Für diesen Reparaturschritt wurden  
  
- die entfernte Kurbel,  
- der Kettenschutz  
- sowie der Kurbelabzieher  
  
gereinigt und anschließend bis zur weiteren Demontage beiseitegelegt.  
  
---  
  
## Erkenntnisse  
  
- ✔ Fengzeo-Kurbelabzieher erfolgreich praktisch eingesetzt.  
- ✔ 16-mm-Maulschlüssel erleichtert den Einsatz erheblich.  
- ✔ Vierkantkurbel konnte ohne Beschädigung entfernt werden.  
- ✔ Kettenschutz lediglich gesteckt.  
- ✔ Verzahnte Dichtung beziehungsweise Ring am Tretlager entdeckt.  
- ✔ Weitere Untersuchung des Tretlagers folgt in einem späteren Arbeitsschritt.  
  
---  
  
## Offene Punkte  
  
- Ausbau der linken Kurbel.  
- Identifikation der gezahnten Dichtung.  
- Bestimmung des tatsächlichen Tretlagerstandards.  
- Ausbau des Tretlagers.

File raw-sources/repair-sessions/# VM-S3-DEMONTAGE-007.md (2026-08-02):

# VM-S3-DEMONTAGE-007  
## Demontage der linken Kurbel  
  
### Metadaten  
  
| Feld | Wert |  
|---|---|
| Baugruppe | Linker Kurbelarm |  
| Status | [BESTÄTIGT] |  
  
---  
  
## Benötigtes Werkzeug  
  
- Kurbelabzieher (Fengzeo)  
- 16-mm-Maulschlüssel  
- Drahtbürste  
- Reiniger  
  
---  
  
## Demontage  
  
Der linke Kurbelarm wurde mit demselben Kurbelabzieher wie zuvor die rechte Seite entfernt.  
  
Der äußere Gewindekörper wurde vollständig in den Kurbelarm eingeschraubt.  
  
Anschließend wurde die Druckspindel mit einem 16-mm-Maulschlüssel angezogen.  
  
Auch auf dieser Seite war ein hoher Kraftaufwand erforderlich.  
  
Die Kurbel löste sich jedoch kontinuierlich und kontrolliert vom Vierkantkonus.  
  
---  
  
## Werkzeugbeobachtung  
  
[BESTÄTIGT]  
  
Der günstige Kurbelabzieher zeigt bereits nach dem Ausbau beider Kurbeln erste Verschleißerscheinungen.  
  
Insbesondere der Druckbolzen besteht vermutlich aus einem weichen Material (möglicherweise Kupfer oder einer vergleichsweise weichen Legierung).  
  
Für einen einmaligen Ausbau scheint das Werkzeug ausreichend.  
  
Die Langzeithaltbarkeit erscheint jedoch begrenzt.  
  
---  
  
## Verbesserungsidee  
  
[ZU PRÜFEN]  
  
Der Druckbolzen des Kurbelabziehers sollte möglichst nicht direkt auf die Bohrung der Tretlagerachse drücken.  
  
Eine größere Auflagefläche wäre günstiger, um punktuelle Belastungen am Innengewinde zu vermeiden.  
  
Hierzu soll künftig der zum Werkzeug gehörende Kunststoffaufsatz näher untersucht werden.

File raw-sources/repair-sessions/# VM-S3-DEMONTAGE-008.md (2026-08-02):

# VM-S3-DEMONTAGE-008  
## Analyse der Kurbelgarnitur  
  
### Kurbel  
  
[BESTÄTIGT]  
  
Auf beiden Kurbelarmen befinden sich folgende Markierungen:  
  
- VanMoof  
- 170 mm  
- Forged  
- GJ-9AS  
  
---  
  
## Kettenblatt  
  
[BESTÄTIGT]  
  
Das originale Kettenblatt besitzt:  
  
- 38 Zähne  
- fünf Befestigungsschrauben  
- austauschbare Konstruktion  
  
Das Kettenblatt kann unabhängig vom Kurbelarm ersetzt werden.  
  
Die Befestigung erfolgt über fünf Innensechskantschrauben.  
  
Zum Gegenhalten besitzt die Rückseite flache Mitnehmerflächen.  
  
---  
  
## Erkenntnis  
  
Der Austausch des Kettenblatts ist grundsätzlich möglich.  
  
Somit lässt sich theoretisch auch eine andere Übersetzung realisieren.  
  
Die eigentliche Kurbelgarnitur bleibt dabei erhalten.  
  
---  
  
## Pedal  
  
[BESTÄTIGT]  
  
Das rechte Pedal konnte mit einem 15-mm-Pedalschlüssel entfernt werden.  
  
Kennzeichnung:  
  
CM-R0H2  
  
Das Pedal weist deutliche Gebrauchsspuren auf.  
  
Eine gründliche Reinigung erscheint ausreichend.

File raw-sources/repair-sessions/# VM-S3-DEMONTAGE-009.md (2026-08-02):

# VM-S3-DEMONTAGE-009  
## Ausbau des Tretlagers  
  
### Wichtige Erkenntnis  
  
[BESTÄTIGT]  
  
Der ursprüngliche Ausbauversuch erfolgte in einer ungünstigen Reihenfolge.  
  
Dadurch entstand zunächst der Eindruck, dass beide Lagerschalen vollständig herausgeschraubt werden müssen.  
  
Während der weiteren Untersuchung stellte sich heraus, dass die Konstruktion anders funktioniert.  
  
---  
  
## Aufbau  
  
Das Tretlager besitzt:  
  
- rechte Schutzkappe (Antriebsseite)  
- linke Lageraufnahme mit Rastnasen  
- Lagereinheit  
- Dichtungen  
  
Die linke Seite dient gleichzeitig als Verdrehschutz des gesamten Tretlagers.  
  
---  
  
## Richtige Demontagereihenfolge  
  
### 1.  
  
Rechte Schutzkappe entfernen.  
  
Antriebsseite.  
  
[BESTÄTIGT]  
  
Diese besitzt Linksgewinde.  
  
Zum Lösen wird daher **im Uhrzeigersinn** gedreht.  
  
---  
  
### 2.  
  
Nach Entfernen der rechten Schutzkappe das komplette Lager von links nach rechts leicht durch den Rahmen schieben.  
  
Dadurch verlassen die Rastnasen auf der linken Seite ihre Führungen.  
  
---  
  
### 3.  
  
Erst jetzt die linke Lagerseite lösen.  
  
Nun lässt sich diese ohne großen Kraftaufwand abschrauben.  
  
---  
  
### 4.  
  
Das komplette Tretlager kann anschließend entnommen werden.  
  
---  
  
## Wichtige Beobachtung  
  
[BESTÄTIGT]  
  
Der erste Ausbauversuch führte zu einem leichten Knacken.  
  
Ursache war vermutlich nicht ein festsitzendes Gewinde.  
  
Vielmehr standen die Rastnasen der linken Lageraufnahme noch unter Spannung.  
  
---  
  
## Werkstatt-Hinweis  
  
Die linke Lagerseite **nicht mit Gewalt lösen**.  
  
Zuerst immer:  
  
- rechte Schutzkappe entfernen,  
- Lager einige Millimeter verschieben,  
- Rastnasen entlasten,  
- anschließend linke Seite abschrauben.  
  
Dadurch werden unnötige Belastungen der Lageraufnahme und des Kabelbaums vermieden.  
  
---  
  
## Gewinde  
  
[BESTÄTIGT]  
  
Rechte Seite:  
  
- Linksgewinde  
  
Linke Seite:  
  
- normales Rechtsgewinde  
  
---  
  
## Reinigung  
  
Nach erfolgreicher Demontage sollen gereinigt werden:  
  
- Lager  
- Dichtungen  
- Lageraufnahmen  
- Kurbelarme  
- Kettenblatt  
  
Anschließend werden alle Bauteile bis zum Wiedereinbau separat eingelagert.

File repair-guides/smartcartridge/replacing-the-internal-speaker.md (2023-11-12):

---
description: >-
  If you don't hear a sound from your Vanmoof, maybe it's just the speaker
  that's broken. /u/Low-Location760 on reddit has the answer.
---

# Replacing the internal speaker

Possible replacement speaker: [https://www.amazon.nl/CQRobot-audioluidspreker-wooferluidspreker-Dupont-interface-verscheidenheid/dp/B09JHSZ7KJ/](https://www.amazon.nl/CQRobot-audioluidspreker-wooferluidspreker-Dupont-interface-verscheidenheid/dp/B09JHSZ7KJ/)

Alternative: [https://www.mouser.de/ProductDetail/CUI-Devices/CES-703316-28PM?qs=wnTfsH77Xs5Aw9YgEqOsGw%3D%3D](https://www.mouser.de/ProductDetail/CUI-Devices/CES-703316-28PM?qs=wnTfsH77Xs5Aw9YgEqOsGw%3D%3D)

Source: [https://www.reddit.com/r/vanmoofbicycle/comments/14w7pv5/fix\_for\_vanmoof\_s3\_with\_no\_sound/](https://www.reddit.com/r/vanmoofbicycle/comments/14w7pv5/fix\_for\_vanmoof\_s3\_with\_no\_sound/)

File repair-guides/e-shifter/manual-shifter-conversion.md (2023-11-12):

---
description: >-
  If you don't want to use the electronic shifter anymore, you can convert the
  whole shifter to manual using a conversion kit developed by /u/VanBood on
  reddit.
---

# Manual shifter conversion

The conversion kits are available from [vanbood.com](http://vanbood.com)

Source: [https://www.reddit.com/r/VanMoofSelfRepair/comments/178j4wm/the\_3d\_printed\_eshifter\_solution\_to\_cure\_vanmoofs/](https://www.reddit.com/r/VanMoofSelfRepair/comments/178j4wm/the\_3d\_printed\_eshifter\_solution\_to\_cure\_vanmoofs/)

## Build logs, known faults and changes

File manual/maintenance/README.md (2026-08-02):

---
description: Cleaning, lubrication, inspection, preservation, and workshop service intervals for the VanMoof S3.
---

# Maintenance

Workshop observations are not manufacturer limits unless explicitly identified below.

## Bottom bracket (WAR-001)

After removal, clean the housing, axle, cups, seals, and chain-cover ring with cleaner, a lint-free cloth, and a brush. Use compressed air cautiously and never spin a bearing at high speed with air. Remove stale grease, let parts dry, and apply fresh bearing grease before installation.

The documented Bafang unit ran smoothly, retained adequate lubrication, and showed no unusual corrosion, so it was considered reusable after service. Slight sensor-body play appeared normal. Replace its cracked right seal; the clean left seal appeared reusable. Inspect the six-pole Higo lead and keep the frame drain opening clear. See the [removal procedure](../disassembly/drivetrain-and-bottom-bracket.md#bafang-bottom-bracket).

## Chain and chain tensioner (WAR-002)

Brush and wipe the chain with a compatible chain cleaner, dry it completely, then apply bicycle-chain lubricant evenly and wipe off the excess. A vice-and-ruler guide was used in the workshop to draw the loose chain through a cloth, but avoid clamping or bending links. Preserve the master link's recorded running direction.

Disassemble the tensioner only in a contained work area because it is spring-loaded. Clean the wheels, `689 RS` bearings, washers, spring, and housing individually. Confirm that bearings turn smoothly, apply only suitable lubricant where required, and keep lubricant away from brakes. Do not return cracked or broken tensioner parts to service.

{% hint style="warning" %}
The chain cleaner used in the workshop attacked a plastic storage container. Check chemical compatibility, ventilation, gloves, disposal instructions, and every polymer part before soaking it.
{% endhint %}

## Corrosion and water management

Clean and assess the kickstand area, lower fork, crank fasteners, tensioner/Shifter area, and brake hardware where corrosion was observed. Use a material-compatible corrosion protectant only after determining whether the damage is superficial. Never contaminate pads or rotors. The bottom-bracket shell drain is intentional and must remain unobstructed.

## Inspection schedule (manufacturer information recorded in the logs)

* **Monthly:** inspect both wheels, handlebar, pedals, saddle, brake pads, and chain; lubricate the chain, clean the frame, and check for applicable firmware updates. Maintain tyre pressure at 40–65 psi.
* **Annually:** service by an authorised VanMoof service partner.
* **Mileage guidance:** chain and sprocket at 6,000–8,000 km; rear hub at 10,000 km.

Intervals do not override inspection after damage, water ingress, abnormal noise, looseness, braking changes, or a crash.

## Kickstand corrosion

Slight corrosion was observed around the removed kickstand. Clean and inspect the precise area and its fastener, then use a compatible light corrosion-protection product. The documented main fastener is an estimated M10 × 30 mm bolt with 8 mm hex and a 10 × 16 × 2.8 mm spring washer; its torque remains unknown.

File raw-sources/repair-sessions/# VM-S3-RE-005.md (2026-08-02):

# VM-S3-RE-005  
## Analyse des Kettenschutzes  
  
### Material  
  
[UNSICHER]  
  
Der Kettenschutz scheint aus einem glasfaserverstärkten Kunststoff (vermutlich PA-GF) zu bestehen.  
  
Eine Materialanalyse steht noch aus.  
  
---  
  
## Zustand  
  
[BESTÄTIGT]  
  
Festgestellte Schäden:  
  
- unterer Haltearm gebrochen  
- mehrere Rastnasen beschädigt  
- deutliche Alterung des Kunststoffs  
  
---  
  
## Bewertung  
  
Die Konstruktion wirkt vergleichsweise filigran.  
  
Ein stabilerer Nachbau erscheint sinnvoll.  
  
Aufgrund der Bauteilgröße wäre vermutlich eine modulare Konstruktion für den 3D-Druck notwendig.  
  
---  
  
## Reverse Engineering  
  
[ZU PRÜFEN]  
  
- Material bestimmen  
- Maße aufnehmen  
- CAD-Modell erstellen  
- modulare Version entwickeln

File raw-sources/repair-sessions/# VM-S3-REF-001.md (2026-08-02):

# VM-S3-REF-001  
# Schrauben- und Befestigungsübersicht  
  
## Metadaten  
  
| Feld | Wert |  
|---|---|
| Kategorie | Referenz |  
| Status | [IN ARBEIT] |  
| Grundlage | Vermessung während vollständiger Demontage |  
  
---  
  
# Untere Akkuabdeckung  
  
## Mittlere Schraube  
  
| Eigenschaft | Wert |  
|---|---|
| Typ | BHCS |  
| Gewinde | M5 (gemessen 4,87 mm) |  
| Länge | 12 mm |  
| Antrieb | Security Torx |  
| Torx-Durchmesser | ca. 4,5–4,6 mm |  
| Anzahl | 1 |  
  
---  
  
## Seitliche Schrauben  
  
| Eigenschaft | Wert |  
|---|---|
| Typ | BHCS |  
| Gewinde | M5 |  
| Länge | 12 mm |  
| Antrieb | Security Torx |  
| Anzahl | 2 |  
  
Unterlegscheiben:  
  
- Stärke: 1,15 mm  
- Außendurchmesser: 10,3 mm  
  
---  
  
# Gummi-/Kunststoffblock  
  
(Befestigungsblock)  
  
## Schrauben  
  
| Eigenschaft | Wert |  
|---|---|
| Typ | SHCS |  
| Gewinde | M5 |  
| Länge | 18 mm |  
| Anzahl | 2 |  
  
Unterlegscheiben:  
  
- Stärke: 0,9 mm  
- Außendurchmesser: 9 mm  
  
---  
  
## Blockabmessungen  
  
| Maß | Wert |  
|---|---|
| Länge | 68,25 mm |  
| Breite | 19,9 mm |  
| Dicke | 18,5 mm |  
  
Langlöcher:  
  
- Länge: 15,75 mm  
- Tiefe: 8,2 mm  
  
Schraubenlöcher:  
  
- Länge: 10,82 mm  
- Breite: 5 mm  
  
---  
  
# Fahrradständer  
  
## Hauptbolzen  
  
| Eigenschaft | Wert |  
|---|---|
| Gewinde | vermutlich M10 |  
| Länge | 30 mm |  
| Innensechskant | 8 mm |  
| Materialmarkierung | 304 |  
  
Federring:  
  
- Innen 10 mm  
- Außen 16 mm  
- Stärke 2,8 mm  
  
---  
  
## Einstellschraube  
  
Innensechskant:  
  
4 mm  
  
---  
  
# Hinterrad  
  
## Achsmuttern  
  
| Eigenschaft | Wert |  
|---|---|
| Gewinde | vermutlich M10 |  
| Anzahl | 2 |  
  
Unterlegscheiben:  
  
- Standard M10  
- Rastscheiben M10  
  
jeweils zwei Stück.  
  
---  
  
# Motorkabelabdeckung  
  
| Typ | SHCS |  
|---|---|
| Gewinde | M4 |  
| Länge | 8 mm |  
| Anzahl | 2 |  
  
---  
  
# Lenkerklemmung  
  
| Typ | BHCS |  
|---|---|
| Gewinde | M6 |  
| Länge | 28 mm |  
| Innensechskant | 5 mm |  
  
Anzahl:  
  
2  
  
---  
  
# Bremshalter  
  
## Lange Schrauben  
  
| Gewinde | M6 |  
|---|----|
| Länge | 18 mm |  
| Typ | BHCS |  
  
---  
  
## Kurze Schrauben  
  
| Gewinde | M6 |  
|---|----|
| Länge | 14 mm |  
| Typ | BHCS |  
  
---  
  
# Kurbel  
  
## Kurbelschrauben  
  
| Gewinde | M8 |  
|---|----|
| Länge | 20 mm |  
| Innensechskant | 8 mm |  
  
Mit Dichtring.  
  
Anzahl:  
  
2  
  
---  
  
# Kettenspanner  
  
| Typ | BHCS |  
|---|---|
| Gewinde | M4 |  
| Länge | 7 mm |  
| Innensechskant | 2,5 mm |  
  
Vermutlich Gehäuseverschluss.  
  
---  
  
# Smart Cartridge  
  
## Befestigung  
  
| Typ | FHCS |  
|---|---|
| Gewinde | M3 |  
| Länge | 8 mm |  
| Antrieb | Security Torx |  
  
Momentan dokumentiert:  
  
8 Schrauben  
  
---  
  
# Frontfender  
  
## Kurze Schrauben  
  
| Gewinde | M5 |  
|---|----|
| Länge | 9 mm |  
| Außensechskant | 8 mm |  
  
Anzahl:  
  
2  
  
---  
  
## Lange Schrauben  
  
| Gewinde | M5 |  
|---|----|
| Länge | 16 mm |  
| Außensechskant | 8 mm |  
  
Anzahl:  
  
4  
  
Gummipuffer:  
  
- Innen 5 mm  
- Außen 10 mm  
- Stärke 6 mm  
  
---  
  
# Antennenabdeckung  
  
| Gewinde | M2,5 |  
|---|---|
| Länge | 6 mm |  
| Typ | Security Torx |  
  
Anzahl:  
  
2  
  
---  
  
# Frontlampe  
  
Madenschraube  
  
| Gewinde | M5 |  
|---|----|
| Länge | 8 mm |  
| Security-Innensechskant | ca. 2,6 mm |  
  
---  
  
# Noch nicht dokumentiert  
  
- zentraler Sicherungsbolzen der Frontgabel  
- Lenkeinschlagbegrenzer  
- zwei Madenschrauben der Schutzblechstreben  
- drei aktuell nicht zugeordnete Schrauben  
  
Status:  
  
[ZU PRÜFEN]

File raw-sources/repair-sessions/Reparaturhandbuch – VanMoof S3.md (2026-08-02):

# Reparaturhandbuch – VanMoof S3  
## VM-S3-HINTERRAD-AKKU-002: Akku-Ausbau, Ständer, Vorderradmotor und Unterlegscheiben  
**Metadaten**  

| Feld | Wert |
| --- | --- |
| Dokumentations-ID | VM-S3-HINTERRAD-AKKU-002 |
| Fahrzeug / Modell | VanMoof S3 |
| Baugruppe | Akku / Hinterrad / Ständer / Vorderradmotor |
| Thema | Ausbau, Zustandsprüfung und Hinweise zur Motorachse |
| Informationsquelle | Audio-Notizen / Apple-Transkript mit nachträglichen Klarstellungen |
| Dokumentationsstatus | Erfahrungswert aus laufender Reparatur |
| Sicherheitsgrad | Gemischt: [BESTÄTIGT] / [UNSICHER] / [ZU PRÜFEN] |

⸻  

## 1. Kurzbeschreibung  
```
[BESTÄTIGT]

```
Bei der dokumentierten Reparatur konnte der Akku erfolgreich ausgebaut werden. Der zugängliche Innenbereich machte dabei einen sauberen Eindruck.  
Für den Ausbau wurde zunächst die Luft aus dem Hinterreifen abgelassen und anschließend der Akku herausgenommen.  
Zusätzlich wurde der Ständer demontiert und auf Korrosion geprüft. Für die Befestigung des Ständers wird ein **8-mm-Inbusschlüssel** benötigt.  
An der Vorderseite wurden die Befestigungen des Vorderradmotors gelöst und die freie Drehbarkeit des Motors kontrolliert.  
Ein wichtiger Montagehinweis betrifft die Motorachse des Vorderradmotors, deren mechanische Formgebung als Verdrehsicherung dient, sowie die korrekte Position der zugehörigen Unterlegscheiben.  

⸻  

## 2. Akku-Ausbau  
```
[BESTÄTIGT]

```
Der Akku konnte erfolgreich ausgebaut werden.  
Die im Transkript genannte Reihenfolge lautet:  
1. Luft aus dem Hinterreifen ablassen.  
2. Akku herausnehmen.  
Der zugängliche Innenbereich machte nach dem Ausbau einen sauberen Eindruck.  
```
[ZU PRÜFEN]

```
* Warum ist das Ablassen der Luft aus dem Hinterreifen für den Akku-Ausbau erforderlich?  
* Wie weit muss der Reifen entlüftet werden?  
* Sind weitere Demontageschritte notwendig, die in dieser Audio-Notiz nicht erwähnt wurden?  
* Welche genaue Ausbauposition beziehungsweise Bewegungsrichtung hat der Akku?  

⸻  

## 3. Ständer  
```
[BESTÄTIGT]

```
Der Ständer wurde demontiert.  
Für die Demontage beziehungsweise Montage des Ständers wird ein **8-mm-Inbusschlüssel** benötigt.  
Dabei wurde eine leichte beziehungsweise beginnende Korrosion festgestellt.  
**Benötigtes Werkzeug**  
```
[BESTÄTIGT]

```
* **8-mm-Inbusschlüssel**  
**Empfohlene zukünftige Maßnahme**  
```
[BESTÄTIGT]

```
Der betroffene Bereich sollte zukünftig:  
* gereinigt und  
* leicht geölt beziehungsweise gegen weitere Korrosion behandelt werden.  
```
[ZU PRÜFEN]

```
* Exakte Position der Korrosion  
* Geeignetes Schmier- oder Korrosionsschutzmittel  
* Zustand der Befestigungsschrauben  
* Schraubenanzahl und Drehmoment des Ständers  

⸻  

## 4. Vorderradmotor und freie Drehbarkeit  
```
[BESTÄTIGT]

```
Die Befestigungen beziehungsweise Radmuttern des Vorderradmotors wurden gelöst. Anschließend wurde die freie Drehbarkeit des Motors geprüft.  
Der Motor dreht weiterhin frei und verhält sich dabei nach subjektiver Einschätzung so gut wie gewohnt.  

⸻  

## 5. Motorachse und mechanische Verdrehsicherung  
```
[BESTÄTIGT]

```
Die Achse des Vorderrads ist gleichzeitig die **Motorachse des Vorderradmotors**.  
Diese Motorachse weist eine mechanische Formgebung beziehungsweise **Haltenase zur Verdrehsicherung** auf. Wenn die Motorachse korrekt in der Aufnahme der Vorderradgabel sitzt, verhindert diese Verdrehsicherung, dass sich die Achse selbst gegenüber der Gabel frei drehen kann.  
Diese Motorachse weist eine mechanische Formgebung beziehungsweise **Haltenase zur Verdrehsicherung** auf. Wenn die Motorachse korrekt in der Aufnahme der Vorderradgabel sitzt, verhindert diese Verdrehsicherung, dass sich die Achse selbst gegenüber der Gabel frei drehen kann.  
Dadurch wird das vom Motor erzeugte Drehmoment auf das Vorderrad übertragen: **Der Motor dreht das Rad, während die Motorachse durch ihre formschlüssige Aufnahme in der Gabel gegen Rotation gesichert bleibt.**  
Dadurch wird das vom Motor erzeugte Drehmoment auf das Vorderrad übertragen: **Der Motor dreht das Rad, während die Motorachse durch ihre formschlüssige Aufnahme in der Gabel gegen Rotation gesichert bleibt.**  
Die Aussage aus dem ursprünglichen Transkript:  
„Da ist die Haltenase im Motor drin.“  
bezieht sich somit auf diese Verdrehsicherung an der Motorachse und **nicht auf eine Haltenase an einer Unterlegscheibe**.  
bezieht sich somit auf diese Verdrehsicherung an der Motorachse und **nicht auf eine Haltenase an einer Unterlegscheibe**.  
**⚠ WICHTIG – Korrekte Position der Motorachse**  
**⚠ WICHTIG – Korrekte Position der Motorachse**  
##   
```
[BESTÄTIGT]

```
##   
Beim Einsetzen des Vorderradmotors muss darauf geachtet werden, dass die Verdrehsicherung der Motorachse korrekt in der dafür vorgesehenen Gabelaufnahme sitzt. Dadurch wird verhindert, dass sich die Motorachse unter dem Motordrehmoment gegenüber der Gabel verdreht.  

⸻  

## 6. Unterlegscheiben an den Radmuttern  
```
[BESTÄTIGT]

```
An der Vorderradachse beziehungsweise an den Radmuttern befinden sich Unterlegscheiben.  
Die vorderen Unterlegscheiben sind **vollständig rund**.  
Die zuvor aus dem Rohtranskript mögliche Interpretation, dass eine Unterlegscheibe selbst eine Haltenase besitzt, ist nicht korrekt. Die erwähnte Haltenase beziehungsweise Verdrehsicherung befindet sich **an der Motorachse selbst**.  
```
[ZU PRÜFEN]

```
* Anzahl der Unterlegscheiben  
* Exakte Position und Reihenfolge der Unterlegscheiben  
* Abmessungen und Material der Unterlegscheiben  
* Exakte Geometrie der Verdrehsicherung an der Motorachse  
* Exakte Form der korrespondierenden Aufnahme an der Vorderradgabel  
* Vorgeschriebenes Anzugsdrehmoment der Radmuttern  

⸻  

## 7. Schrauben, Muttern und Befestigungsmittel  

| Position | Befestigungsmittel | Anzahl | Größe | Werkzeug | Besonderheit | Status |
| --- | --- | --- | --- | --- | --- | --- |
| Vorderradmotor / Motorachse | Radmuttern | Nicht genannt | Nicht genannt | Nicht genannt | Befestigung der Motorachse | [BESTÄTIGT] |
| Vorderradmotor / Motorachse | Unterlegscheiben | Nicht genannt | Nicht genannt | – | Vollständig rund | [BESTÄTIGT] |
| Motorachse | Mechanische Verdrehsicherung | Bestandteil der Achse | Nicht genannt | – | Verhindert Rotation der Achse in der Gabelaufnahme | [BESTÄTIGT] |
| Ständer | Befestigungsschrauben | Nicht genannt | Nicht genannt | 8-mm-Inbusschlüssel | Leichte Korrosion im Bereich festgestellt | [BESTÄTIGT] |

⸻  

## 8. Werkzeugliste  

| Werkzeug | Verwendung | Status |
| --- | --- | --- |
| 8-mm-Inbusschlüssel | Demontage und Montage des Ständers | [BESTÄTIGT] |

⸻  

## 9. Zustandsbefunde  

| Bauteil / Bereich | Festgestellter Zustand | Status |
| --- | --- | --- |
| Innenbereich nach Akku-Ausbau | Sieht sauber aus | [BESTÄTIGT] |
| Ständer beziehungsweise dessen Bereich | Leichte beziehungsweise beginnende Korrosion | [BESTÄTIGT] |
| Vorderradmotor | Dreht frei und nach subjektiver Einschätzung weiterhin gut | [BESTÄTIGT] |

⸻  

## 10. Erfahrungswissen / Werkstatthinweise  
```
[BESTÄTIGT]

```
**Akku-Ausbau:** Vor dem Herausnehmen des Akkus wurde die Luft aus dem Hinterreifen abgelassen.  
**Ständer:** Für die Demontage beziehungsweise Montage des Ständers wird ein **8-mm-Inbusschlüssel** benötigt.  
**Ständer:** Für die Demontage beziehungsweise Montage des Ständers wird ein **8-mm-Inbusschlüssel** benötigt.  
**Korrosion:** Der Bereich des Ständers sollte aufgrund beginnender Korrosion zukünftig gereinigt und mit einem geeigneten Mittel behandelt werden.  
**Vorderradmotor:** Nach dem Lösen der Befestigung wurde die freie Drehbarkeit des Motors kontrolliert.  
**Motorachse:** Die Motorachse verfügt über eine mechanische Verdrehsicherung. Beim Einsetzen des Vorderradmotors muss die Achse korrekt in der Gabelaufnahme positioniert werden.  
**Unterlegscheiben:** Beim Zusammenbau auf die korrekte Position und Reihenfolge aller Unterlegscheiben und Radmuttern achten.  

⸻  

## 11. Hinweis zur gesprochenen Bezeichnung „574“  
```
[BESTÄTIGT]

```
Die im ursprünglichen Transkript erwähnte Zahl **„574“** ist keine Fahrradnummer, Bauteilnummer, Auftragsnummer oder sonstige technische Kennzeichnung.  
Sie war ein **sarkastischer Verweis darauf, dass das Fahrrad bereits sehr häufig auseinandergebaut und repariert werden musste**.  
Sie war ein **sarkastischer Verweis darauf, dass das Fahrrad bereits sehr häufig auseinandergebaut und repariert werden musste**.  
Die Zahl besitzt daher keine technische Bedeutung und wird nicht als technisches Metadatum verwendet.  

⸻  

## 12. Offene Punkte für zukünftige Reparaturen  
```
[ZU PRÜFEN]

```
* Genaue Reihenfolge aller Schritte beim Akku-Ausbau  
* Grund für das Ablassen der Luft aus dem Hinterreifen  
* Exakte Position der Korrosion am Ständer beziehungsweise an dessen Befestigung  
* Anzahl der Ständerbefestigungsschrauben  
* Anzugsdrehmoment der Ständerbefestigung  
* Anzahl und Größe der Radmuttern  
* Anzahl, Position und Reihenfolge der Unterlegscheiben  
* Exakte Geometrie der Verdrehsicherung an der Motorachse  
* Exakte Form der korrespondierenden Gabelaufnahme  
* Vorgeschriebenes Anzugsdrehmoment der Radmuttern  
* Geeignetes Schmier- beziehungsweise Korrosionsschutzmittel für den Ständerbereich  

⸻  

## 13. Änderungs- und Erkenntnisprotokoll  

| Version | Quelle | Änderung |
| --- | --- | --- |
| 0.1 | Zweite Audio-Notiz | Ersterfassung von Akku-Ausbau, Zustand des Innenbereichs, Korrosion am Ständer, Prüfung des Vorderradmotors und Hinweisen zu Unterlegscheiben und Motorachse |
| 0.2 | Nachträgliche Klarstellung | Präzisierung der Haltenase als Verdrehsicherung an der Motorachse; Klarstellung der technischen Funktion; Einordnung von „574“ als sarkastische Bemerkung ohne technische Bedeutung |
| 0.3 | Kurze Audio-Ergänzung | Ergänzung des 8-mm-Inbusschlüssels als benötigtes Werkzeug für die Demontage beziehungsweise Montage des Ständers |

⸻  

## 14. Quellenhinweis  
Dieser Dokumentationsbaustein wurde aus während der Reparatur erstellten Audio-Notizen beziehungsweise deren automatischen Apple-Transkripten sowie anschließenden mündlichen Klarstellungen abgeleitet.  
Offensichtliche sprachliche Wiederholungen und erkennbare Transkriptionsfehler wurden bereinigt. Technische Informationen wurden nur dann als [BESTÄTIGT] markiert, wenn sie ausdrücklich genannt, nachträglich eindeutig klargestellt oder eindeutig aus der beschriebenen Handlung hervorgegangen sind.  
Nicht eindeutig rekonstruierbare Aussagen werden als [UNSICHER] markiert. Informationen, die für ein vollständiges Reparaturhandbuch noch fehlen, sind als [ZU PRÜFEN] gekennzeichnet.  

⸻  

## 15. Rohquellen-Zuordnung  
**Quelle:** Zweite Audio-Notiz / Apple-Transkript sowie kurze Audio-Ergänzung  
**Behandelte Themen:**  
**Behandelte Themen:**  
* Akku-Ausbau  
* Ablassen der Luft aus dem Hinterreifen  
* Zustand des Innenbereichs  
* Demontage und Korrosionszustand des Ständers  
* 8-mm-Inbusschlüssel für den Ständer  
* Lösen des Vorderradmotors  
* Prüfung der freien Drehbarkeit des Motors  
* Unterlegscheiben an den Radmuttern  
* Verdrehsicherung an der Motorachse  
**Nachträgliche Klarstellungen:**  
* Die erwähnte Haltenase ist Bestandteil beziehungsweise Formmerkmal der Motorachse und dient als Verdrehsicherung.  
* Die Verdrehsicherung verhindert, dass sich die Motorachse gegenüber der Gabelaufnahme frei dreht, sodass das Motordrehmoment das Vorderrad antreibt.  
* Die Zahl „574“ war eine sarkastische Bemerkung und hat keine technische Bedeutung.  
* Für die Demontage beziehungsweise Montage des Ständers wird ein 8-mm-Inbusschlüssel benötigt.

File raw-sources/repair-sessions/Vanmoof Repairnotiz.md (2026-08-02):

# Vanmoof Repairnotiz   
  
# Reparaturhandbuch – VanMoof S3  
## VM-S3-HINTERRAD-AKKU-002: Akku-Ausbau, Ständer, Vorderradmotor und Unterlegscheiben  
**Metadaten**  

| Feld | Wert |
| --- | --- |
| Dokumentations-ID | VM-S3-HINTERRAD-AKKU-002 |
| Fahrzeug / Modell | VanMoof S3 |
| Baugruppe | Akku / Hinterrad / Ständer / Vorderradmotor |
| Thema | Ausbau, Zustandsprüfung und Hinweise zur Motorachse |
| Informationsquelle | Audio-Notiz / Apple-Transkript mit nachträglicher Klarstellung |
| Dokumentationsstatus | Erfahrungswert aus laufender Reparatur |
| Sicherheitsgrad | Gemischt: [BESTÄTIGT] / [UNSICHER] / [ZU PRÜFEN] |

⸻  

## 1. Kurzbeschreibung  
```
[BESTÄTIGT]

```
Bei der dokumentierten Reparatur konnte der Akku erfolgreich ausgebaut werden. Der zugängliche Innenbereich machte dabei einen sauberen Eindruck.  
Für den Ausbau wurde zunächst die Luft aus dem Hinterreifen abgelassen und anschließend der Akku herausgenommen.  
Zusätzlich wurde der Ständer demontiert und auf Korrosion geprüft. An der Vorderseite wurden die Befestigungen des Vorderradmotors gelöst und die freie Drehbarkeit des Motors kontrolliert.  
Ein wichtiger Montagehinweis betrifft die Motorachse des Vorderradmotors, deren mechanische Formgebung als Verdrehsicherung dient, sowie die korrekte Position der zugehörigen Unterlegscheiben.  

⸻  

## 2. Akku-Ausbau  
```
[BESTÄTIGT]

```
Der Akku konnte erfolgreich ausgebaut werden.  
Die im Transkript genannte Reihenfolge lautet:  
1. Luft aus dem Hinterreifen ablassen.  
2. Akku herausnehmen.  
Der zugängliche Innenbereich machte nach dem Ausbau einen sauberen Eindruck.  
```
[ZU PRÜFEN]

```
* Warum ist das Ablassen der Luft aus dem Hinterreifen für den Akku-Ausbau erforderlich?  
* Wie weit muss der Reifen entlüftet werden?  
* Sind weitere Demontageschritte notwendig, die in dieser Audio-Notiz nicht erwähnt wurden?  
* Welche genaue Ausbauposition beziehungsweise Bewegungsrichtung hat der Akku?  

⸻  

## 3. Ständer  
```
[BESTÄTIGT]

```
Der Ständer wurde demontiert.  
Dabei wurde eine leichte beziehungsweise beginnende Korrosion festgestellt.  
**Empfohlene zukünftige Maßnahme**  
```
[BESTÄTIGT]

```
Der betroffene Bereich sollte zukünftig:  
* gereinigt und  
* leicht geölt beziehungsweise gegen weitere Korrosion behandelt werden.  
```
[ZU PRÜFEN]

```
* Exakte Position der Korrosion  
* Geeignetes Schmier- oder Korrosionsschutzmittel  
* Zustand der Befestigungsschrauben  
* Schraubenanzahl, Größe und Drehmoment des Ständers  

⸻  

## 4. Vorderradmotor und freie Drehbarkeit  
```
[BESTÄTIGT]

```
Die Befestigungen beziehungsweise Radmuttern des Vorderradmotors wurden gelöst. Anschließend wurde die freie Drehbarkeit des Motors geprüft.  
Der Motor dreht weiterhin frei und verhält sich dabei nach subjektiver Einschätzung so gut wie gewohnt.  

⸻  

## 5. Motorachse und mechanische Verdrehsicherung  
```
[BESTÄTIGT]

```
Die Achse des Vorderrads ist gleichzeitig die **Motorachse des Vorderradmotors**.  
Diese Motorachse weist eine mechanische Formgebung beziehungsweise **Haltenase zur Verdrehsicherung** auf. Wenn die Motorachse korrekt in der Aufnahme der Vorderradgabel sitzt, verhindert diese Verdrehsicherung, dass sich die Achse selbst gegenüber der Gabel frei drehen kann.  
Dadurch wird das vom Motor erzeugte Drehmoment auf das Vorderrad übertragen: **Der Motor dreht das Rad, während die Motorachse durch ihre formschlüssige Aufnahme in der Gabel gegen Rotation gesichert bleibt.**  
Die Aussage aus dem ursprünglichen Transkript:  
„Da ist die Haltenase im Motor drin.“  
bezieht sich somit auf diese Verdrehsicherung an der Motorachse und **nicht auf eine Haltenase an einer Unterlegscheibe**.  
**⚠ WICHTIG – Korrekte Position der Motorachse**  
##   
```
[BESTÄTIGT]

```
##   
Beim Einsetzen des Vorderradmotors muss darauf geachtet werden, dass die Verdrehsicherung der Motorachse korrekt in der dafür vorgesehenen Gabelaufnahme sitzt. Dadurch wird verhindert, dass sich die Motorachse unter dem Motordrehmoment gegenüber der Gabel verdreht.  

⸻  

## 6. Unterlegscheiben an den Radmuttern  
```
[BESTÄTIGT]

```
An der Vorderradachse beziehungsweise an den Radmuttern befinden sich Unterlegscheiben.  
Die vorderen Unterlegscheiben sind **vollständig rund**.  
Die zuvor aus dem Rohtranskript mögliche Interpretation, dass eine Unterlegscheibe selbst eine Haltenase besitzt, ist nicht korrekt. Die erwähnte Haltenase beziehungsweise Verdrehsicherung befindet sich **an der Motorachse selbst**.  
```
[ZU PRÜFEN]

```
* Anzahl der Unterlegscheiben  
* Exakte Position und Reihenfolge der Unterlegscheiben  
* Abmessungen und Material der Unterlegscheiben  
* Exakte Geometrie der Verdrehsicherung an der Motorachse  
* Exakte Form der korrespondierenden Aufnahme an der Vorderradgabel  
* Vorgeschriebenes Anzugsdrehmoment der Radmuttern  

⸻  

## 7. Schrauben, Muttern und Befestigungsmittel  

| Position | Befestigungsmittel | Anzahl | Größe | Besonderheit | Status |
| --- | --- | --- | --- | --- | --- |
| Vorderradmotor / Motorachse | Radmuttern | Nicht genannt | Nicht genannt | Befestigung der Motorachse | [BESTÄTIGT] |
| Vorderradmotor / Motorachse | Unterlegscheiben | Nicht genannt | Nicht genannt | Vollständig rund | [BESTÄTIGT] |
| Motorachse | Mechanische Verdrehsicherung | Bestandteil der Achse | Nicht genannt | Verhindert Rotation der Achse in der Gabelaufnahme | [BESTÄTIGT] |
| Ständer | Befestigungsschrauben | Nicht genannt | Nicht genannt | Leichte Korrosion im Bereich festgestellt | [ZU PRÜFEN] |

⸻  

## 8. Zustandsbefunde  

| Bauteil / Bereich | Festgestellter Zustand | Status |
| --- | --- | --- |
| Innenbereich nach Akku-Ausbau | Sieht sauber aus | [BESTÄTIGT] |
| Ständer beziehungsweise dessen Bereich | Leichte beziehungsweise beginnende Korrosion | [BESTÄTIGT] |
| Vorderradmotor | Dreht frei und nach subjektiver Einschätzung weiterhin gut | [BESTÄTIGT] |

⸻  

## 9. Erfahrungswissen / Werkstatthinweise  
```
[BESTÄTIGT]

```
**Akku-Ausbau:** Vor dem Herausnehmen des Akkus wurde die Luft aus dem Hinterreifen abgelassen.  
**Korrosion:** Der Bereich des Ständers sollte aufgrund beginnender Korrosion zukünftig gereinigt und mit einem geeigneten Mittel behandelt werden.  
**Vorderradmotor:** Nach dem Lösen der Befestigung wurde die freie Drehbarkeit des Motors kontrolliert.  
**Motorachse:** Die Motorachse verfügt über eine mechanische Verdrehsicherung. Beim Einsetzen des Vorderradmotors muss die Achse korrekt in der Gabelaufnahme positioniert werden.  
**Unterlegscheiben:** Beim Zusammenbau auf die korrekte Position und Reihenfolge aller Unterlegscheiben und Radmuttern achten.  

⸻  

## 10. Hinweis zur gesprochenen Bezeichnung „574“  
```
[BESTÄTIGT]

```
Die im ursprünglichen Transkript erwähnte Zahl **„574“** ist keine Fahrradnummer, Bauteilnummer, Auftragsnummer oder sonstige technische Kennzeichnung.  
Sie war ein **sarkastischer Verweis darauf, dass das Fahrrad bereits sehr häufig auseinandergebaut und repariert werden musste**.  
Die Zahl besitzt daher keine technische Bedeutung und wird nicht als technisches Metadatum verwendet.  

⸻  

## 11. Offene Punkte für zukünftige Reparaturen  
```
[ZU PRÜFEN]

```
* Genaue Reihenfolge aller Schritte beim Akku-Ausbau  
* Grund für das Ablassen der Luft aus dem Hinterreifen  
* Exakte Position der Korrosion am Ständer beziehungsweise an dessen Befestigung  
* Anzahl und Größe der Ständerbefestigungsschrauben  
* Anzahl und Größe der Radmuttern  
* Anzahl, Position und Reihenfolge der Unterlegscheiben  
* Exakte Geometrie der Verdrehsicherung an der Motorachse  
* Exakte Form der korrespondierenden Gabelaufnahme  
* Vorgeschriebenes Anzugsdrehmoment der Radmuttern  
* Geeignetes Schmier- beziehungsweise Korrosionsschutzmittel für den Ständerbereich  

⸻  

## 12. Änderungs- und Erkenntnisprotokoll  

| Version | Quelle | Änderung |
| --- | --- | --- |
| 0.1 | Zweite Audio-Notiz | Ersterfassung von Akku-Ausbau, Zustand des Innenbereichs, Korrosion am Ständer, Prüfung des Vorderradmotors und Hinweisen zu Unterlegscheiben und Motorachse |
| 0.2 | Nachträgliche Klarstellung | Präzisierung der Haltenase als Verdrehsicherung an der Motorachse; Klarstellung der technischen Funktion; Einordnung von „574“ als sarkastische Bemerkung ohne technische Bedeutung |

⸻  

## 13. Quellenhinweis  
Dieser Dokumentationsbaustein wurde aus einer während der Reparatur erstellten Audio-Notiz beziehungsweise deren automatischem Apple-Transkript sowie einer anschließenden mündlichen Klarstellung abgeleitet.  
Offensichtliche sprachliche Wiederholungen und erkennbare Transkriptionsfehler wurden bereinigt. Technische Informationen wurden nur dann als [BESTÄTIGT] markiert, wenn sie ausdrücklich genannt, nachträglich eindeutig klargestellt oder eindeutig aus der beschriebenen Handlung hervorgegangen sind.  
Nicht eindeutig rekonstruierbare Aussagen werden als [UNSICHER] markiert. Informationen, die für ein vollständiges Reparaturhandbuch noch fehlen, sind als [ZU PRÜFEN] gekennzeichnet.  

⸻  

## 14. Rohquellen-Zuordnung  
**Quelle:** Zweite Audio-Notiz / Apple-Transkript  
**Behandelte Themen:**  
* Akku-Ausbau  
* Ablassen der Luft aus dem Hinterreifen  
* Zustand des Innenbereichs  
* Demontage und Korrosionszustand des Ständers  
* Lösen des Vorderradmotors  
* Prüfung der freien Drehbarkeit des Motors  
* Unterlegscheiben an den Radmuttern  
* Verdrehsicherung an der Motorachse  
**Nachträgliche Klarstellungen:**  
* Die erwähnte Haltenase ist Bestandteil beziehungsweise Formmerkmal der Motorachse und dient als Verdrehsicherung.  
* Die Verdrehsicherung verhindert, dass sich die Motorachse gegenüber der Gabelaufnahme frei dreht, sodass das Motordrehmoment das Vorderrad antreibt.  
* Die Zahl „574“ war eine sarkastische Bemerkung und hat keine technische Bedeutung.

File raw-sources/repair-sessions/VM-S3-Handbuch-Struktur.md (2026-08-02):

# VM-S3-Handbuch

## Ordnerstruktur

``` text
VM-S3-Handbuch/
│
├── 00_Referenz/
│   ├── REF-001 Schraubenübersicht
│   ├── REF-002 Drehmomente
│   ├── REF-003 Werkzeuge
│   ├── REF-004 Steckverbinder
│   ├── REF-005 Lager & Dichtungen
│   └── REF-006 Ersatzteile
│
├── 01_Demontage/
│   ├── DEM-001 ...
│   ├── DEM-002 ...
│   └── ...
│
├── 02_Montage/
│   ├── MON-001 ...
│   └── ...
│
├── 03_Wartung/
│   ├── WAR-001 Reinigung Tretlager
│   ├── WAR-002 Kette konservieren
│   └── ...
│
├── 04_ReverseEngineering/
│   ├── RE-001 Kettenschutz
│   ├── RE-002 Tretlager
│   ├── RE-003 Kabelbaum
│   └── ...
│
└── 05_Anhang/
    ├── Teilelisten
    ├── Fotos
    ├── CAD
    └── STL
```

## Hinweise

### Referenzbereich

-   Schraubenübersicht
-   Anzugsdrehmomente
-   Werkzeuge
-   Steckverbinder
-   Lager & Dichtungen
-   Ersatzteile

### Demontage

Chronologische Zerlegung des Fahrrads.

### Montage

Zusammenbau in umgekehrter Reihenfolge mit Verweisen auf die
Referenzkapitel.

### Wartung

Reinigung, Schmierung, Inspektion und Konservierung.

### Reverse Engineering

Analyse der Konstruktion, Materialien, Schwachstellen und
Eigenentwicklungen.

### Anhang

Fotos, CAD-Dateien, STL-Dateien und ergänzende Teilelisten.

## Geplante Erweiterungen

  Feld                  Beschreibung
  --------------------- ---------------------------------------------
  Werkzeug              Erforderlicher Schlüssel oder Bit
  Drehmoment            Herstellerangabe oder praktisch verifiziert
  VanMoof-Teilenummer   Falls bekannt
  Kapitel               Verweis auf Demontage-/Montagekapitel
  Foto                  Referenzbild der Schraube

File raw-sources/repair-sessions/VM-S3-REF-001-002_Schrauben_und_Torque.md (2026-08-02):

# VM-S3-REF-001

# Schrauben- und Befestigungsübersicht

  ------------------------------------------------------------------------------------------------------------------------------------------------------------------
  ID        Baugruppe                Typ                Gewinde        Länge   Antrieb                   Werkzeug         Drehmoment   Anzahl   Bemerkung
  --------- ------------------------ ------------------ -------------- ------- ------------------------- ---------------- ------------ -------- --------------------
  SCR-001   Akkuabdeckung unten      BHCS               M5             12 mm   Security Torx             T25 Security (zu --           1        identisch mit
            (Mitte)                                                                                      prüfen)                                seitlichen Schrauben

  SCR-002   Akkuabdeckung unten      BHCS               M5             12 mm   Security Torx             T25 Security (zu --           2        mit Unterlegscheibe
            (Seite)                                                                                      prüfen)                                

  SCR-003   Gummi-/Kunststoffblock   SHCS               M5             18 mm   Innensechskant            4 mm Inbus       --           2        

  SCR-004   Fahrradständer           SHCS               M10            30 mm   8 mm Innensechskant       8 mm Inbus       --           1        Materialmarkierung
                                                        (vermutlich)                                                                            304

  SCR-005   Ständerverstellung       Madenschraube      unbekannt      --      4 mm Innensechskant       4 mm Inbus       --           1        

  SCR-006   Hinterrad-Achsmutter     Sechskantmutter    M10            --      Sechskant                 Steckschlüssel   **30 Nm**    2        Herstellerangabe
                                                        (vermutlich)                                                                            

  SCR-007   Motorkabelabdeckung      SHCS               M4             8 mm    3 mm Innensechskant       3 mm Inbus       **2 Nm**     2        Herstellerangabe

  SCR-008   Lenkerklemmung           BHCS               M6             28 mm   5 mm Innensechskant       5 mm Inbus       **7 Nm**     2        Herstellerangabe

  SCR-009   Bremshalter (lang)       BHCS               M6             18 mm   5 mm Innensechskant       5 mm Inbus       --           2        

  SCR-010   Bremshebel / Haltering   BHCS               M6             14 mm   5 mm Innensechskant       5 mm Inbus       --           2        
            (kurz)                                                                                                                              

  SCR-011   Selbstschneidende        selbstschneidend   M5             12 mm   4 mm Innensechskant       4 mm Inbus       --           1        RDX A2-70
            Schraube                                                                                                                            

  SCR-012   Halter unbekannt         SHCS               M5             18 mm   4 mm Innensechskant       4 mm Inbus       --           2        Zuordnung prüfen

  SCR-013   Kurbelschraube           SHCS               M8             20 mm   8 mm Innensechskant       8 mm Inbus       --           2        mit Gummiring

  SCR-014   Kettenspanner            BHCS               M4             7 mm    2,5 mm Innensechskant     2,5 mm Inbus     --           1        Gehäusedeckel

  SCR-015   Smart Cartridge          FHCS               M3             8 mm    Security Torx             Security Torx    --           8        Cartridge / Socket

  SCR-016   Frontfender (kurz)       Sechskant          M5             9 mm    SW8 + Kreuz               SW8              --           2        

  SCR-017   Frontfender (lang)       Sechskant          M5             16 mm   SW8 + Kreuz               SW8              --           4        mit Gummipuffer

  SCR-018   Antennenabdeckung        Senkkopf           M2,5           6 mm    Security Torx             Security Torx    --           2        

  SCR-019   Frontlampe               Madenschraube      M5             8 mm    Security-Innensechskant   Security-Inbus   --           1        

  SCR-020   Kettenspanner            FHCS               M4             18 mm   Innensechskant            3 mm Inbus       --           1        Befestigung

  SCR-021   Kettenspanner            BHCS               M4             ca. 24  Innensechskant            3 mm Inbus       --           1        Befestigung
                                                                       mm                                                                       
  ------------------------------------------------------------------------------------------------------------------------------------------------------------------

# VM-S3-REF-002

# Anzugsdrehmomente

> Quelle: VanMoof Support Chatbot\
> Status: Herstellerangabe

  Baugruppe                       Drehmoment
  ----------------------------- ------------
  Lenkerklemmung                        7 Nm
  Steuersatz-Vorspannschraube          12 Nm
  Sattelstützenklemme                  10 Nm
  Sattelklemmung                       10 Nm
  Vorderrad-Achsmuttern                30 Nm
  Hinterrad-Achsmuttern                30 Nm
  Motorkabelabdeckung                   2 Nm
  Pedale                               40 Nm

## Noch ohne Herstellerangabe

-   Akkuabdeckung
-   Tretlager
-   Kurbeln
-   Kettenspanner
-   Schutzbleche
-   Smart Cartridge
-   Frontlampe
-   Antennenabdeckung
-   Fahrradständer
-   Bremszangen
-   Gepäckträger

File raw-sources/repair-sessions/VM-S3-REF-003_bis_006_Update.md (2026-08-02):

# VanMoof S3 Referenz -- Update

## VM-S3-REF-003 -- Offizielle Ersatzteile (VanMoof)

  Bauteil                         Preis
  ----------------------------- -------
  Cartridge                       484 €
  Akku                            605 €
  Motor                           200 €
  Vorderrad inkl. Motor           330 €
  Hinterrad inkl. 2-Gang-Nabe     250 €
  Chain Cover                      25 €
  Chain Tensioner                  40 €
  Socket                          159 €
  Kick Lock Set                    66 €
  Lenkerset                       189 €
  Bremssattel                      70 €
  Bremsbeläge                      15 €
  Bremsscheibe                     10 €
  Schutzblech vorne                30 €
  Schutzblech hinten               30 €
  Kickstand                        25 €
  Seatpost Clamp                   10 €
  Buttons                          19 €
  Griffe                           15 €

### Chain Cover

Status: **\[HERSTELLERANGABE\]**

-   offizielles Ersatzteil
-   Preis: 25 €
-   Material unbekannt
-   Teilenummer unbekannt

------------------------------------------------------------------------

## VM-S3-REF-004 -- Wartungsintervalle

### Jährlich

-   Wartung durch autorisierten VanMoof Service Partner

### Monatlich

-   Vorder- und Hinterrad prüfen
-   Lenker prüfen
-   Pedale prüfen
-   Sattel prüfen
-   Bremsbeläge prüfen
-   Reifendruck: 40--65 PSI
-   Kette prüfen und schmieren
-   Rahmen reinigen
-   Firmware aktualisieren

### Laufleistung

-   Kette/Ritzel: 6.000--8.000 km
-   Hinterradnabe: 10.000 km

### Hersteller-Drehmomente

  Bauteil                 Nm
  --------------------- ----
  Vorbau                   7
  Headset                 12
  Sattelstützenklemme     10
  Sattel                  10
  Vorderachse             30
  Hinterachse             30
  Motorkabelabdeckung      2
  Pedale                  40

------------------------------------------------------------------------

## VM-S3-REF-005 -- Fehlercodes

  Fehler   Bedeutung
  -------- ---------------
  0--20    Batterie/BMS
  21       Ladegerät
  40       Klingeltaster
  41       Boost-Taster
  44       E-Shifter
  45--53   Motor
  54--58   SIM/GSM

Empfohlene Maßnahmen: - Firmware aktualisieren - Bike zurücksetzen -
Neustart - Bei Error 21 Ladegerät neu verbinden - Bei Error 44
E-Shifter-Kabel prüfen

------------------------------------------------------------------------

## VM-S3-REF-006 -- Firmware

  Version   Änderungen
  --------- --------------------------------------------
  1.9.3     Unlock, Batteriemanagement, Error Handling
  1.9.1     Vorbereitung 1.9.3
  1.8.2     Power-Level-Reset behoben
  1.8.1     Deep Sleep, Error 57
  1.7.6     Error 16 behoben
  1.7.2     Manuelles Schalten, Fehler 12/13
  1.7.1     Fehler 13/16
  1.6.13    PowerBank vorbereitet
  1.6.8     E-Shifter verbessert

Erkenntnisse: - Mehrfach verbessertes Batteriemanagement - Mehrfach
überarbeiteter E-Shifter - Keine Hardware-Revisionen dokumentiert

------------------------------------------------------------------------

## Pedale

Status: **\[HERSTELLERANGABE\]**

-   Keine Schmierung erforderlich
-   Rechtsgewinde rechts
-   Linksgewinde links
-   6-mm-Innensechskant
-   40 Nm

### Werkstattpraxis

Eine dünne Schicht Montagefett oder Anti-Seize wird häufig verwendet,
ist jedoch keine offizielle VanMoof-Empfehlung.

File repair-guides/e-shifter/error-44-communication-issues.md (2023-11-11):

---
description: >-
  Err44 one of the most common errors with the Vanmoof S3, it points to a
  communication issue with the bikes eShifter. This issue can often be fixed
  quite cheaply using just a few electronic components.
cover: ../../.gitbook/assets/3ae689ba-56e1-4569-a2ad-4a34a7880634.PNG
coverY: 0
---

# Error 44 / Communication issues

So heres how to diagnose and fix it - most of the time.

**A few important things beforehand:**

\- I'll be describing the debugging without an external Lab-Powersupply using only the bikes power. Please be careful not to short anything on the 24V line or the RX line you'll probably kill your bike if you do. (Almost happened to me, sending 24V though the tx lines is no bueno).

\- If you have access to a lab power supply USE IT, it makes things much easier and you are much less likely to fry your bike.

\- I take no responsibility if you fry your bike trying to fix the shifter. You need to know your way around electronics.

**Tools you'll need:**

\- tools for disassembling the shifter and bike (Vanmoof Toolbox, various allen keys)

\- digital multimeter

\- soldering iron

\- tweezers (for potential desoldering of smd parts)

\- wire

\- replacement parts (mostly assortment of SMD resistors)

\

**Getting to the board**

1. Err44 indicates a communication issue with your shifter. To diagnose this you'll need to disassemble your eShifter to gain access to the eShifters circuit board. So remove the shifter from your bike (See Vanmoof Howtos here: [https://www.youtube.com/watch?v=qehoD-6xbkI](https://www.youtube.com/watch?v=qehoD-6xbkI) and here [https://www.youtube.com/watch?v=FyDecZQhlAw](https://www.youtube.com/watch?v=FyDecZQhlAw\&pp=ygUvdmFubW9vZiBzMyAgaG93IHRvIHJlcGxhY2Ugc2hpZnRlciByZXBsYWNlbWVudCA%3D))
2. Next open it up by removing the 4 screw holding the eShifter together. You can split the housing open by using a flat-screwdriver or a knife and slowly wiggling it in from the bottom (there is a slighty rougher area on the bottom where this can be done quite easily)
3. The pcb is located in the front-half of the eShifter housing. It's secured on 3 small plastic protrusions, you should be able to take the pcb out by scraping away a bit of these protrusions and then lever the pcb out carefully with a flathead screwdriver.

**Diagnosing the board**

1. One simple test you can do to quickly rule out the motor, before taking a look at the board is to apply 5V to the terminals of the motor and see if it's spinning. If it does your motor should generally be fine.
2. Now onto the board - remove the PCB from the front half and turn it around so the backside faces you. There are 6 silver points on the backside, these are testpoints. We will be using these to roughly pinpoint the possible cause of your problems.
3. Solder two wires onto the testpoints in the top right corner and connect them to your multimeter in voltage measuring mode. Now turn off your bike and connect the shifter to your bike. Turn on your bike and pay close attention to your multimeter during the first seconds of the bikes startup, your multimeter should read 5V. If it doesn't your problem is most likely related to the power-circuit of your eShifter or bike. Turn your bike off and disconnect the shifter.
4. To rule out an error on the low voltage side of the board, before messing with the dc regulator, put your multimeter in resistance measuring mode and measure the resistance of the output capacitor C10. The resistance should be rising while you measure, as you're charging the capacitor with your multimeter during measuring, increasing its resistance. If you do not get an increase in resistance here, this means that the circuitry is somehow drawing power from the capacitor faster than your multimeter can charge it, usually this means there is a short somewhere on your board, making debugging more tedious. If this is not the case, you're good to continue with the DC regulator.
5. To figure out what the problem is we will need to measure a few points closer to the dc regulator, while the board is powered.**DANGER!!** Please **be very careful** when doing this! A little slip-up with the multimeter probe might otherwise connect two parts of the circuit that wont like talking to each other.
6. First of all we need to make sure the DC-Regulator actually receives enough input power from the cartridge of the bike, measure from the VIN pin of the DC-Regulator (usually the one in the middle on the top side of the regulator U4 on the board) against ground. You should be reading around 24V here. If you don't get 24V, the main culprit here will probably be one of the bridge resistors near the power input(the lines coming down from the 4-pin plug). So measure the resistance of both bridge resistors (L1 and L5) and see that you get 0 resistance there. Replace them if you get any significant resistance on L1 or L5.
7. Next measure the voltage on the FB pin of the regulator (this is the lower right one). You should be reading 0.8V here, which is the voltage the regulator tries maintain at this pin. If you do see 0.8V here but don't get 5V on the output, measure the resistance of the voltage divider resistors R5 and R6. R5 should read 270kOhm and R6 should read 51kOhm, replace the resistors with the correct value if the resistance is off. If you don't get 0.8V here, either the DC-regulator or the resistors R5 or R6 might most likely be faulty. Measure the resistors and replace them if necessary, if the resistors are good you can try to replace the dc-regulator with the AOZ1280-CI regulator.
8. Now connect the shifter and reboot the bike again and measure the testpoints from earlier again. If you fixed the 5V supply and have no other issue on the board, you should see the Err44 go away as soon as the bike has finished booting and started talking to the shifter-pcb again.
9. If Err 44 still remains and your 5V line is fixed, you should next measure the resistance on R17 and R18, which should both be at 22Ohms, replace the resistors when needed. This should fix 99% of all problems related to Err44.
10. Another possible cause might be a faulty ESD protection diode ED1, measure the resistance for ED1 in all directions and you should be getting a high resistance from the rx/tx lines towards ground and a lower resistance in the other direction.
11. To check if the shifter works you can connect the motor to the pcb and then see if the motors starts spinning when you start the bike. This is the default behaviour of the shifter as it tries to move the gear into its initial position 1.

**Further debugging you can do**

\- Measure the hall-effect sensors by soldering leads to the testpoints near the hall sensors. See if the hall-sensors are properly latching when a magnet passes over them.

\- Measure the resistance of resistor R680, it should be around 0,68Ohms, replace the resistor if the value is off.

\- Measure the voltage using the motor testpoints next to the motor driver IC (U3) and see if you get enough output here, but usually this is not a problem, the driver IC is pretty robust.

\

I hope this helps some of you in fixing your shifter, while the IC might be a problem too, it usually comes down to the resistors and DC-regulator. The IC is usually only affected if you accidentally put 24V through the UART lines, as I did when trying to fix mine ;-D

**Update:** here is a first draft of a schematic for the eshifter.

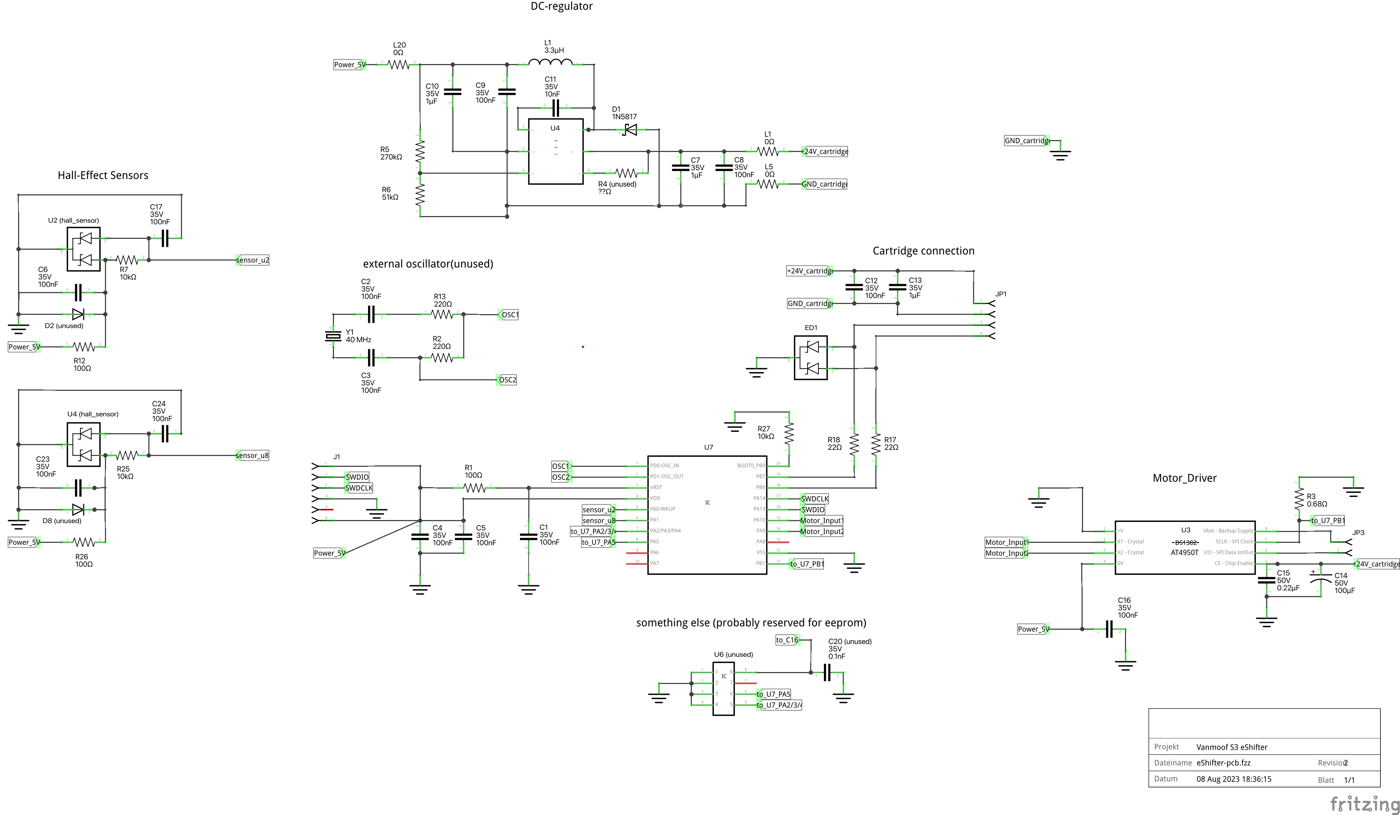
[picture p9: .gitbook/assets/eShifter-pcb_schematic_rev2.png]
<figure><figcaption><p>the reverse engineered eShifter schematic. </p></figcaption></figure>

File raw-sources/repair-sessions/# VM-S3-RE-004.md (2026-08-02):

# VM-S3-RE-004  
## Analyse der Tretlagerdichtungen  
  
### Rechte Dichtung  
  
[BESTÄTIGT]  
  
Die rechte Dichtung weist einen deutlichen Riss auf.  
  
Das Gummimaterial ist gebrochen.  
  
Ein Austausch wird empfohlen.  
  
---  
  
### Linke Dichtung  
  
[BESTÄTIGT]  
  
Die linke Dichtung befindet sich nahezu im Neuzustand.  
  
Nach Reinigung kann sie weiterverwendet werden.  
  
---  
  
## Ausbau  
  
Die Dichtungen lassen sich vorsichtig mit einem kleinen Schraubendreher aus den Lagerschalen herausheben.  
  
---  
  
## Vermutung  
  
[UNSICHER]  
  
Es handelt sich vermutlich um Standard-Bafang-Ersatzteile.  
  
Ein Nachdruck erscheint daher wahrscheinlich nicht notwendig.

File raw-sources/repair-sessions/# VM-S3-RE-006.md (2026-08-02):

# VM-S3-RE-006  
## Rahmenanalyse  
  
### Wasserablauf  
  
[BESTÄTIGT]  
  
Im Bereich des Tretlagergehäuses befindet sich eine Wasserablauföffnung.  
  
Diese ermöglicht das Ablaufen eingedrungener Feuchtigkeit.  
  
---  
  
## Bewertung  
  
Die Konstruktion zeigt, dass VanMoof an Feuchtigkeit im Rahmen gedacht hat.  
  
Trotz der bekannten Schwächen wurde dieser Bereich konstruktiv sinnvoll ausgeführt.

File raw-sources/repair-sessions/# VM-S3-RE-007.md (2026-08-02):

# VM-S3-RE-007  
## Identifikation der Bremskomponenten  
  
### Vorderer Bremssattel  
  
Kennzeichnung:  
  
- J19 8380  
  
---  
  
### Hinterer Bremssattel  
  
Kennzeichnung:  
  
- J19 7901  
  
---  
  
## Zweck  
  
Die Kennzeichnungen dienen der späteren Identifikation kompatibler Ersatzteile.

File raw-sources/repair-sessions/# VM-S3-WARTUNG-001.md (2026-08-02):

# VM-S3-WARTUNG-001  
## Reinigung und Zustandsanalyse des Bafang-Tretlagers  
  
### Metadaten  
  
| Feld | Wert |  
|---|---|
| Baugruppe | Bafang-Tretlager |  
| Status | [BESTÄTIGT] |  
| Arbeitsschritt | Reinigung und Begutachtung |  
  
---  
  
## Reinigung  
  
Nach der vollständigen Demontage wurde das Tretlager gereinigt.  
  
Verwendete Hilfsmittel:  
  
- Drahtbürste  
- Reiniger  
- fusselfreies Tuch  
- Druckluft  
  
Folgende Bauteile wurden gereinigt:  
  
- Lagergehäuse  
- Lagerachse  
- rechte Lagerschale  
- linke Lagerschale  
- Dichtungen  
- Kettenschutzring  
  
---  
  
## Lagerzustand  
  
[BESTÄTIGT]  
  
Das Lager befindet sich trotz seines Alters insgesamt in einem guten Zustand.  
  
Feststellungen:  
  
- keine auffälligen Korrosionsschäden  
- Lager laufen leichtgängig  
- vorhandene Schmierung ausreichend  
- Wiedereinbau nach Reinigung möglich  
  
---  
  
## Sensor  
  
[BESTÄTIGT]  
  
Der Sensorkörper besitzt konstruktionsbedingt ein leichtes Spiel auf der Achse.  
  
Dieses Spiel scheint normal zu sein und stellt vermutlich keinen Defekt dar.  
  
---  
  
## Steckverbinder  
  
Kennzeichnung:  
  
- Hersteller: Higo  
- 6-poliger wasserdichter Stecker  
- weißer Farbpunkt  
- Kennzeichnung: 03  
  
---  
  
## Werkstatt-Hinweis  
  
Vor dem Wiedereinbau empfiehlt sich:  
  
- alte Fettreste entfernen  
- Lager mit Druckluft ausblasen  
- anschließend neues Lagerfett aufbringen

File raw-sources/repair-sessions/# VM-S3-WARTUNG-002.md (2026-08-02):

# VM-S3-WARTUNG-002  
## Reinigung und Konservierung der Kette  
  
### Reinigung  
  
Die Kette wurde mechanisch gereinigt.  
  
Verwendet wurden:  
  
- Bürste  
- Reiniger  
- Tuch  
  
Zur Reinigung wurde zusätzlich eine Führung aus Schraubstock und Zollstock genutzt, um die Kette kontrolliert hindurchzuziehen.  
  
---  
  
## Konservierung  
  
Nach der Reinigung wurde die Kette vollständig mit Kettenspray behandelt.  
  
Anschließend erfolgte die Lagerung in einem verschlossenen Zip-Beutel.  
  
---  
  
## Ziel  
  
Korrosion während der Lagerung verhindern.

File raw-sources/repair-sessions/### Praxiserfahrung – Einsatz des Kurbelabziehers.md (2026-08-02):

### Praxiserfahrung – Einsatz des Kurbelabziehers  
  
`[BESTÄTIGT]`  
  
Während des Abziehvorgangs wurde der Kurbelarm mit einer Hand festgehalten, während mit der anderen Hand über einen 16-mm-Maulschlüssel die Druckspindel des Kurbelabziehers angezogen wurde.  
  
Das Festhalten dient dabei **nicht** dazu, einen plötzlich abspringenden Kurbelarm aufzufangen. Der Kurbelabzieher löst den Presssitz kontrolliert und führt den Kurbelarm langsam von der Vierkantachse herunter.  
  
Der Kurbelarm wurde vielmehr als Gegenlager genutzt, um den zum Drehen der Druckspindel erforderlichen Kraftaufwand aufzubringen.  
  
In der Praxis hat sich eine Arbeitsposition bewährt, bei der:  
  
- der Maulschlüssel in einem Winkel von ungefähr **30°** zum Kurbelarm angesetzt wird,  
- eine Hand den Kurbelarm hält,  
- die andere Hand den Maulschlüssel bewegt,  
- beide Hände kontrolliert gegeneinander drücken.  
  
Dadurch lässt sich der notwendige Kraftaufwand in kleinen Schritten aufbauen, ohne den Kurbelarm zusätzlich blockieren oder das Fahrrad anderweitig fixieren zu müssen.  
  
> **Werkstatt-Hinweis**  
>  
> Der Kurbelabzieher arbeitet kontrolliert gegen den Presssitz der Vierkantaufnahme. Das Lösen erfolgt kontinuierlich und nicht schlagartig. Ein kontrollierter Kraftaufbau erleichtert die Demontage erheblich.

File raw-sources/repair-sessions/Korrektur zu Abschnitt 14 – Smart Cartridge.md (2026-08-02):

**Korrektur zu Abschnitt 14 – Smart Cartridge**  
```
[BESTÄTIGT]

```
Für die Demontage der Smart Cartridge wird ein **Torx-T9-Schlüssel beziehungsweise Torx-T9-Bit** benötigt.  
Die im automatischen Transkript als „Neuner Talks“ wiedergegebene Werkzeuggröße wurde nachträglich bestätigt.  
**Befestigungsschrauben**  
```
[BESTÄTIGT]

```
* Kurze Senkkopfschrauben gehören zur Smart Cartridge.  
* Lange Flachkopfschrauben gehören zur Antennenabdeckung.  
```
[ZU PRÜFEN]

```
* Werkzeugtyp und Werkzeuggröße der langen Flachkopfschrauben  
* Ob alle kurzen Senkkopfschrauben ebenfalls mit Torx T9 betätigt werden  
* Anzahl, Gewindegröße und Länge beider Schraubentypen  
* Vorgeschriebene Anzugsdrehmomente  

⸻  

**Ergänzung zur Werkzeugliste**  

| Werkzeug | Verwendung | Status |
| --- | --- | --- |
| Torx T9  | Ausbau der Smart Cartridge | [BESTÄTIGT] |

⸻  

**Allgemeiner Werkstatthinweis**  
```
[BESTÄTIGT]

```
Am VanMoof S3 wird ein großer Teil der Befestigungsschrauben mit **Inbusschlüsseln** gelöst beziehungsweise montiert.  
Diese allgemeine Beobachtung ersetzt jedoch nicht die konkrete Prüfung der Werkzeugaufnahme an jeder einzelnen Schraube. Insbesondere bei der Smart Cartridge kommen auch **Torx-Schrauben** zum Einsatz.  

⸻  

**Ergänzung zum Änderungsprotokoll**  

| Version | Quelle | Änderung |
| --- | --- | --- |
| 0.3 | Nachträgliche Klarstellung | Torx T9 für die Smart Cartridge bestätigt; Werkzeugtyp der Senk- und Flachkopfschrauben bleibt teilweise offen; allgemeiner Hinweis auf überwiegend verwendete Inbusschrauben ergänzt |

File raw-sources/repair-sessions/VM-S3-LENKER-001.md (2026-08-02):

# Reparaturhandbuch -- VanMoof S3

## VM-S3-LENKER-001: Kabelführung bei Demontage und Montage des Lenkers

### Metadaten

  Feld                   Wert
  ---------------------- ----------------------------------------
  Dokumentations-ID      `VM-S3-LENKER-001`
  Fahrzeug / Modell      VanMoof S3
  Baugruppe              Lenker / Frontbereich
  Thema                  Kabelführung bei Demontage und Montage
  Informationsquelle     Audio-Notiz / Apple-Transkript
  Dokumentationsstatus   Erster Erfahrungswert
  Sicherheitsgrad        `[BESTÄTIGT]`

------------------------------------------------------------------------

## 1. Kurzbeschreibung

`[BESTÄTIGT]`

Bei Reparaturarbeiten am **VanMoof S3** muss vor dem Abnehmen
beziehungsweise erneuten Montieren des Lenkers auf die korrekte Führung
der im Lenker verlaufenden Kabel geachtet werden.

Die Kabel müssen vor der Demontage beziehungsweise Montage über die
Öffnung an der Vorderseite unterhalb des Lenkers ausreichend
herausgezogen werden. Andernfalls besteht die Gefahr, dass sie beim
Zusammenbau im Bereich des Gabelschafts eingeklemmt und beschädigt
werden.

------------------------------------------------------------------------

## 2. Betroffene Bauteile

`[BESTÄTIGT]`

-   Lenker
-   Gummistopfen an der Vorderseite beziehungsweise Unterseite des
    Lenkers
-   Zwei im Lenker verlaufende Kabel
-   Gabelschaft beziehungsweise die von unten in den Lenkerbereich
    hineinragende Frontgabelstange

`[ZU PRÜFEN]`

-   Exakte Bezeichnung und Funktion der beiden Kabel
-   Exakte Position und Form der Kabeldurchführung
-   Offizielle technische Bezeichnung des hier als Gabelschaft
    beziehungsweise Frontgabelstange bezeichneten Bauteils

------------------------------------------------------------------------

## 3. Benötigte Werkzeuge

`[BESTÄTIGT]`

Für das Herausziehen der Kabel kann eines der folgenden kleinen
Werkzeuge verwendet werden:

-   kleine Zange
-   kleiner Haken

`[ZU PRÜFEN]`

Die genaue Werkzeugart und optimale Größe wurden nicht spezifiziert.

------------------------------------------------------------------------

## 4. Vorgehensweise

### Schritt 1 -- Gummistopfen entfernen

`[BESTÄTIGT]`

Vor Arbeiten am Lenker zunächst den **Gummistopfen vorne an der
Unterseite des Lenkers entfernen**.

### Schritt 2 -- Kabel herausziehen

`[BESTÄTIGT]`

Mit einer kleinen Zange oder einem kleinen Haken die dort verlaufenden
Kabel vorsichtig durch die Öffnung nach unten herausziehen.

Die Kabel müssen so positioniert werden, dass sie nicht zu weit in den
Bereich hineinragen, in dem der Gabelschaft beziehungsweise die
Frontgabelstange von unten in den Lenkerbereich hineinragt.

### Schritt 3 -- Lenker demontieren oder montieren

`[BESTÄTIGT]`

Erst nachdem die Kabel ausreichend herausgezogen und aus dem gefährdeten
Bereich entfernt wurden, sollte der Lenker abgenommen beziehungsweise
wieder montiert werden.

Beim Zusammenbau darauf achten, dass die Kabel nicht zwischen Lenker und
Gabelschaft eingeklemmt werden.

------------------------------------------------------------------------

## 5. Technischer Hintergrund

`[BESTÄTIGT]`

Die beiden Kabel verlaufen horizontal im oberen Bereich des Lenkers.
Wenn sie zu weit in den Bereich des Gabelschafts hineinragen, reicht der
dort vorhandene Platz für beide Kabel nicht aus.

Beim Aufsetzen beziehungsweise Festziehen des Lenkers kann der
Gabelschaft gegen die Kabel drücken. Dadurch können die Kabel gequetscht
und beschädigt werden.

------------------------------------------------------------------------

## 6. Warnhinweis

> **⚠ WARNUNG -- Gefahr von Kabelschäden**
>
> `[BESTÄTIGT]`
>
> Vor der Demontage und insbesondere vor der erneuten Montage des
> Lenkers müssen die beiden Kabel über die Öffnung unterhalb des Lenkers
> ausreichend herausgezogen werden.
>
> Werden die Kabel im Bereich des Gabelschafts belassen, können sie beim
> Zusammenbau eingeklemmt oder gequetscht werden.

------------------------------------------------------------------------

## 7. Besonderheit bei fehlenden Spacern

`[BESTÄTIGT]`

Besondere Vorsicht ist erforderlich, wenn **keine Spacer im
Lenkerbereich verbaut sind**. In diesem Fall steht weniger Freiraum zur
Verfügung, wodurch das Risiko steigt, dass die Kabel beim Zusammenbau
gequetscht werden.

`[UNSICHER]`

Die abschließende Aussage im ursprünglichen Transkript bezüglich der
Spacer war aufgrund eines Transkriptionsfehlers nicht vollständig
eindeutig:

> „Deswegen immer nur mit Spaceon und mit diesem rausgezogenen Kabel
> fahren."

Vermutlich bezieht sich die Aussage auf die korrekte Montage mit Spacern
und herausgezogenen beziehungsweise korrekt positionierten Kabeln. Die
genaue technische Aussage sollte bei einer zukünftigen Reparatur
nochmals verifiziert werden.

------------------------------------------------------------------------

## 8. Schrauben und Befestigungsmittel

In diesem Dokumentationsabschnitt wurden **keine konkreten Schrauben,
Größen, Längen oder Anzahlen genannt**.

  Position     Anzahl Gewindegröße   Länge   Werkzeug   Status
  ---------- -------- -------------- ------- ---------- -------------------------
  --               -- --             --      --         Keine Angaben vorhanden

------------------------------------------------------------------------

## 9. Erfahrungswissen / Werkstatthinweis

`[BESTÄTIGT]`

**Merksatz:** Vor dem Abnehmen und erneuten Montieren des Lenkers immer
zuerst den unteren Gummistopfen entfernen und die beiden Kabel
ausreichend herausziehen. Dadurch wird verhindert, dass die Kabel beim
Zusammenbau durch den Gabelschaft gequetscht werden.

------------------------------------------------------------------------

## 10. Offene Punkte für zukünftige Reparaturen

`[ZU PRÜFEN]`

-   Welche genaue Funktion haben die beiden Kabel?
-   Wie weit müssen die Kabel idealerweise herausgezogen werden?
-   Welche Spacer sind vorgesehen und welche Abmessungen haben sie?
-   Ist die Montage ohne Spacer technisch zulässig oder lediglich mit
    erhöhtem Risiko verbunden?
-   Wie lautet die genaue Bezeichnung des Gummistopfens beziehungsweise
    der Kabeldurchführung?
-   Gibt es ein definiertes Drehmoment für die Lenkerbefestigung?
-   Welche Schrauben werden zur Befestigung des Lenkers verwendet?
-   Können Fotos der korrekten und fehlerhaften Kabelführung ergänzt
    werden?

------------------------------------------------------------------------

## 11. Änderungs- und Erkenntnisprotokoll

  -----------------------------------------------------------------------
  Version                 Quelle                  Änderung
  ----------------------- ----------------------- -----------------------
  0.1                     Erste Audio-Notiz       Ersterfassung der
                                                  Kabelführung und des
                                                  Risikos einer
                                                  Kabelquetschung bei der
                                                  Lenkermontage

  -----------------------------------------------------------------------

------------------------------------------------------------------------

## 12. Quellenhinweis

Dieser Dokumentationsbaustein wurde aus einer während beziehungsweise im
Zusammenhang mit Reparaturarbeiten erstellten Audio-Notiz abgeleitet.
Offensichtliche sprachliche Wiederholungen und Transkriptionsfehler
wurden bereinigt. Technische Informationen wurden nur dann als
`[BESTÄTIGT]` markiert, wenn sie ausdrücklich genannt wurden oder
eindeutig aus der beschriebenen Handlung hervorgingen. Unsichere
Interpretationen sind entsprechend gekennzeichnet.

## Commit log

2023-11-03 initial commit, inkl. some parts and dummy readme
    [cable_retention_cap.3mf, handlebar_adjustment_sleeve.3mf, stem_retention_cap.3mf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]
2023-11-12 GITBOOK-10: added section for removal of front wheel
2023-11-12 GITBOOK-11: added section on opening up the front motor
2023-11-12 GITBOOK-12: added replacement part info on hub-gears
2023-11-12 GITBOOK-15: added error 4 and 6, as well as hub motor sensor schematic and manual shifter conversion by vanbood
2026-08-02 Document S3 fasteners and torque specifications
